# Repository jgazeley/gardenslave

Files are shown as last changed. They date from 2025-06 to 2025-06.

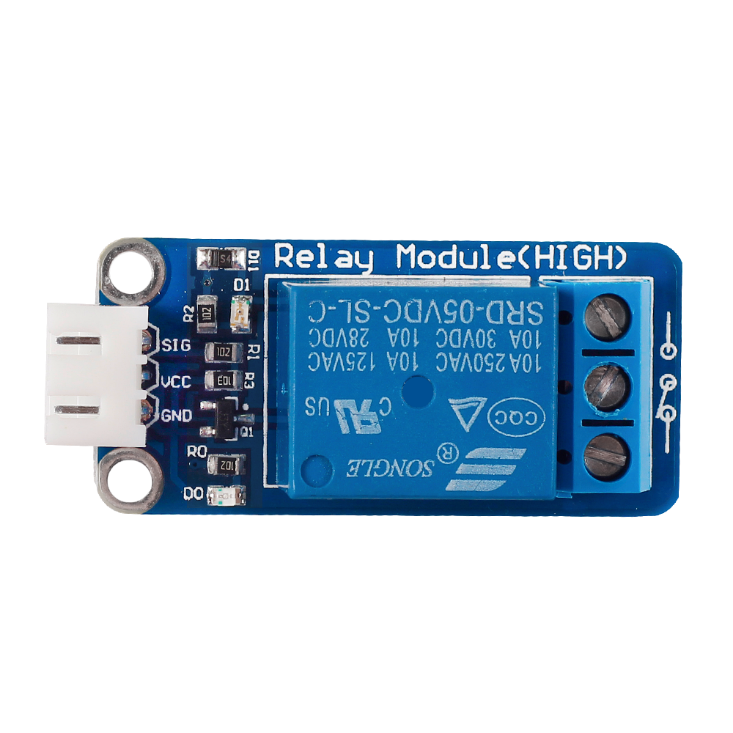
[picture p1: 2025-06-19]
docs/relay-photo.png

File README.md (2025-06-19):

# GardenSlave

**Autonomous Plant Watering System**  
Raspberry Pi Pico (or Arduino Nano) → Soil Moisture Sensor → 12V Water Pump → Float-Switch Alarm

---

## Overview

GardenSlave automates irrigation:

- **Soil Moisture Monitoring**  
  Reads an analog moisture probe on **A2**; if the raw reading ≥ `DryValue` (600), the pump runs for 1 s every 6 s.

- **Tank-Level Detection**  
  Float switch on **GP6** (`INPUT_PULLUP`) senses “empty” when HIGH:  
  1. Watering halts and SOS melody loops (`Sos()`).  
  2. Upon refill, `Zelda()` plays once, then normal watering resumes.

- **Dual-Platform Support**  
  By default `#define PICO` (GP27 buzzer, GP16 pump).  
  Uncomment the `#ifdef NANO` block to use an Arduino Nano (D11, D13, A2).

---

## PCB & 3D Model
**PCB:**
GardenSlave PCB  
*Top view of the GardenSlave PCB in KiCad showing the Pico, relay, buck converter, and connector footprints.*

KiCad 3D View  
*KiCad 3D render of the PCB layout.*

**3D Printed Enclosure:**
GardenSlave Enclosure  
*GardenSlave installed in a custom 3D-printed enclosure, with openings for the soil sensor cable and pump power lead.*

Assembled Unit in Operation  
*GardenSlave powered up and connected to the reservoir float switch and soil probe.*

---

## Wiring & Pinout

| Signal | Pico GPIO / Nano Pin | Code Name |
| --- | --- | --- |
| **Buzzer** | GP27 / D11 | `buzzer` |
| **Float Switch** | GP6 / D6 | `float_sensor` |
| **Pump Relay** | GP16 / D13 | `pump` |
| **Soil Moisture**| A2 (GP26 on Pico) | — |

### Parts

- **Moisture Sensor Connector**  
  Connector Header Through Hole, Right-Angle, 3-position, 0.098″ (2.50 mm)  
  [JST S3B-XH-A (Digikey #1651048)](https://www.digikey.com/en/products/detail/jst-sales-america-inc/S3B-XH-A/1651048)

- **Float Switch**  
  6 Pieces Plastic PP Float Switch for Fish-Tank Liquid Level Sensing  
  [Anndason DP5200 (Amazon #B072QCHQ2P)](https://www.amazon.com/dp/B072QCHQ2P)

- **Pump Power Connector**  
  Connector Header Through Hole, Right-Angle, 2-position  
  [Molex 1724480002 (Digikey #5116918)](https://www.digikey.com/en/products/detail/molex/1724480002/5116918)

- **Buck Converter (12V to 5V)**  
  DC-DC Buck Converter Module, adjustable output (e.g. 24 V→5 V/9 V/12 V/3 V)  
  [eBoot MP1584EN (Amazon #B07RVG34WR)](https://www.amazon.com/dp/B07RVG34WR)

- **Relay**  
  5 V DC Mini Power Relay (SPDT) - Auto PCB Mount Electric Relay With 5 Pins for Universal Household Appliance  
  [Songle SRD-05VDC-SL-C (Amazon #B098JPM9S7)](https://www.amazon.com/dp/B098JPM9S7)

- **Relay Driver Transistor**  
  30pcs S9013H Transistor Plastic-Encapsulate Power TO-92 Transistor NPN 25V 500mA 625mW  
  [uxcell S9013H (Amazon #B07KPBS9VK)](https://www.amazon.com/dp/B07KPBS9VK)

- **Piezo Buzzer**  
  10pcs DC5V Black Mini Active Piezo Buzzers Electronic Buzzer Alarm Sounder Speaker Beep Tone    
  [mxuteuk HF-12095 (Amazon #B07VK1GJ9X)](https://www.amazon.com/dp/B07VK1GJ9X)

---

## Calibration Constants

```cpp
const int AirValue      = 632;  // ADC in air (dry)
const int WaterValue    = 450;  // ADC in water (wet)
const int DryValue      = 600;  // soilMoistureValue ≥ this → pump on

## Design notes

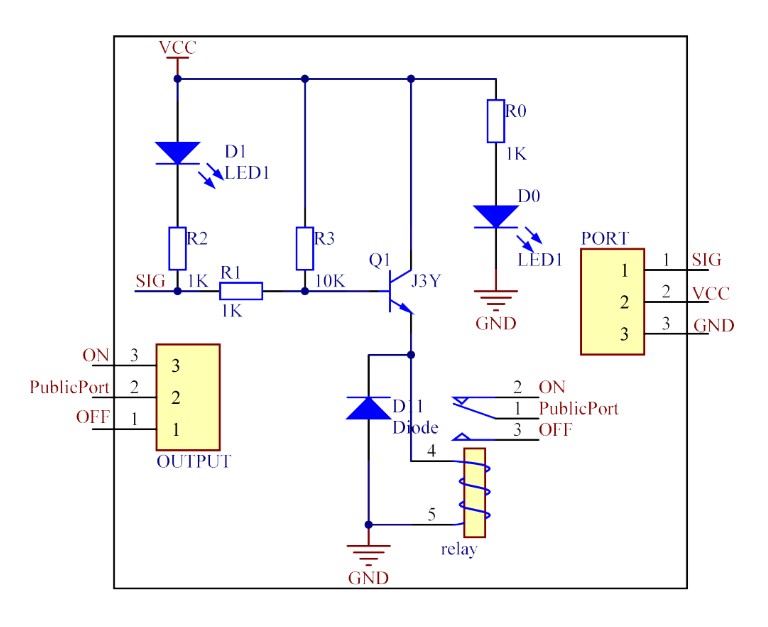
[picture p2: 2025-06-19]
docs/relay-schematic.jpg

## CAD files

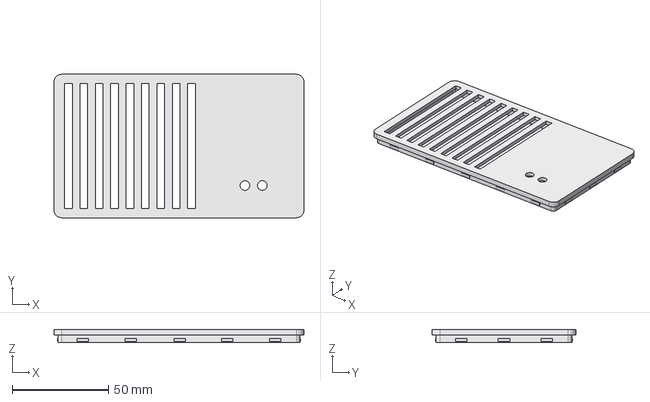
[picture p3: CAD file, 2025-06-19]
enclosure/freecad/garden3D.FCStd
130.0 x 74.6 x 7.00 mm

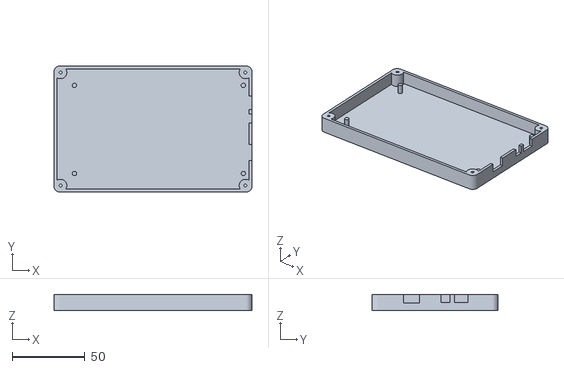
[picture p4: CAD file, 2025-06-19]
enclosure/stl/gardenslave_bottom.stl
136.0 x 86.6 x 11.2

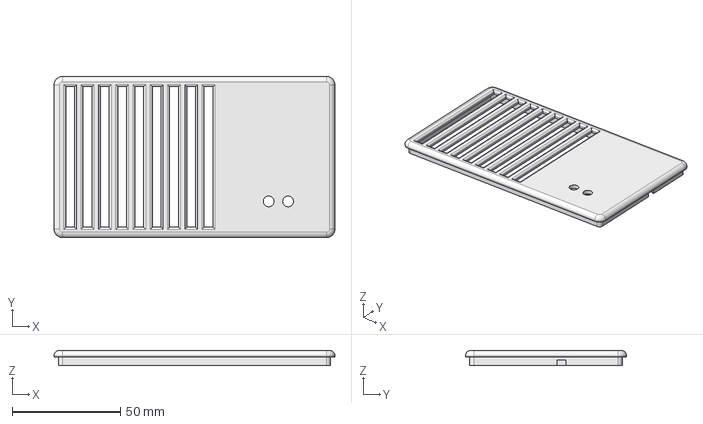
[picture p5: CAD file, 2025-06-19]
enclosure/freecad/garden3D_top.FCStd
130.0 x 74.6 x 7.00 mm

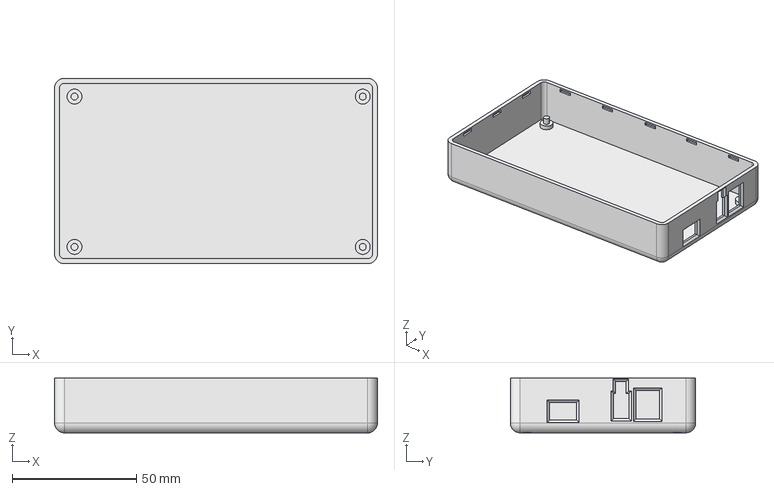
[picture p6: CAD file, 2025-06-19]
enclosure/freecad/garden3D_btm.FCStd
130.0 x 74.6 x 22.0 mm

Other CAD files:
enclosure/stl/gardenslave_top.stl

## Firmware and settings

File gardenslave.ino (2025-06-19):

// Uncomment the target platform and recompile:
// #define NANO
#define PICO

// Pin definitions for Raspberry Pi Pico
#ifdef PICO
  const int buzzer       = 27; // Piezo buzzer output pin
  const int float_sensor = 6;  // Float switch input pin (active-LOW with pullup)
  const int pump         = 16; // Water pump control pin
#endif

// Pin definitions for Arduino Nano (disabled)
// #ifdef NANO
//   const int buzzer       = 11;
//   const int float_sensor = 6;
//   const int pump         = 13;
//   const int pump2        = 18; // second pump (if needed)
// #endif

// Soil moisture calibration (raw ADC values)
const int AirValue   = 632; // reading in air (dry)
const int WaterValue = 450; // reading in water (wet)
const int DryValue = 600;   // dry threshold
int soilMoistureValue   = 0; // raw ADC reading
int soilMoistureValue2  = 0; // (unused) second sensor reading
int soilMoisturePercent = 0; // mapped percentage (0–100)

// Buzzer melodies: delays for SOS, frequencies for Zelda tune
int sos[]   = { 100,100,100, 300,300,300, 100,100,100 };
int zelda[] = { 784,740,622,440,415,659,831,1047 };

bool low_water = false; // state of the float switch

void setup() {
  pinMode(buzzer, OUTPUT);          // buzzer as output
  pinMode(float_sensor, INPUT_PULLUP); // float switch with internal pull-up
  pinMode(pump, OUTPUT);            // pump as output
  // #ifdef NANO
  //   pinMode(pump2, OUTPUT);        // optional second pump
  // #endif
}

// Play SOS: 3 short, 3 long, 3 short tones
void Sos() {
  for (int i = 0; i < 9; i++) {
    tone(buzzer, 1047);            // fixed pitch
    delay(sos[i]);                 // short or long duration
    noTone(buzzer);                // stop tone
    delay(100);                    // brief pause
    if (i == 2 || i == 5 || i == 8) {
      delay(400);                  // pause between letters
    }
  }
}

// Play Zelda melody: eight notes
void Zelda() {
  for (int i = 0; i < 8; i++) {
    tone(buzzer, zelda[i]);        // play each frequency
    delay(140);                    // fixed note length
  }
  noTone(buzzer);                  // stop buzzer at end
}

// Main control loop
void loop() {
  // Read float switch (LOW when water present)
  low_water = digitalRead(float_sensor);

  if (!low_water) {
    // If float switch indicates water, check soil moisture
    soilMoistureValue = analogRead(A2); // raw reading from moisture sensor

    if (soilMoistureValue >= DryValue) {
      // If very dry, run pump for 1 second, then wait 5 seconds
      digitalWrite(pump, HIGH);
      delay(1000);
      digitalWrite(pump, LOW);
      delay(5000);
    }

    // Optional second pump logic (commented out)
    // soilMoistureValue2 = analogRead(A1);
    // if (soilMoistureValue2 >= 600) {
    //   digitalWrite(pump2, HIGH);
    //   delay(1000);
    //   digitalWrite(pump2, LOW);
    //   delay(5000);
    // }
  }

  if (low_water) {
    // If tank is empty, repeatedly sound SOS until refilled
    while (digitalRead(float_sensor)) {
      Sos();
    }
    // Once float switch reads water again, play Zelda tune once
    Zelda();
  }
}

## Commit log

2025-06-19 Added 3d and pcb files
    [garden3D.FCStd, garden3D_btm.FCStd, garden3D_top.FCStd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]
2025-06-19 Fixed DryValue and README
    [gardenslave.ino]
2025-06-19 Refactor project structure
    [garden3D.FCStd, garden3D_btm.FCStd, garden3D_top.FCStd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]
2025-06-19 Add gerber.zip
